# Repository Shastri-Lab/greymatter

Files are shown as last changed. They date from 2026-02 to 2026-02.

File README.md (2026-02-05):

# greymatter DAC controller

Embedded firmware for the Raspberry Pi Pico 2 (RP2350) controlling a multi-board DAC system for precision analog output generation. Designed for photonic neural network research applications.

## Features

- **24 DAC Control**: 8 daughter boards, each with 3 DACs (2x current, 1x voltage)
- **High Channel Count**: 112 current outputs + 32 voltage outputs = 144 total channels
- **SCPI Interface**: Standard instrument control commands over USB serial
- **Precision Output**:
  - Current: 3.125 mA to 300 mA full-scale (LTC2662)
  - Voltage: ±2.5V to ±10V bipolar, 0-10V unipolar (LTC2664)
- **16-bit Resolution**: 65,536 steps per channel
- **Fault Monitoring**: Per-DAC fault detection with interrupt support

## Hardware Requirements

- Raspberry Pi Pico 2 (RP2350)
- Greymatter motherboard with:
  - 3x MCP23S17 I/O expanders
  - TXB0106 level shifter
  - 8 daughter board slots
- Microcyte daughter boards (per slot):
  - 2x LTC2662 current DAC (5 channels each)
  - 1x LTC2664 voltage DAC (4 channels)

## Quick Start

### Prerequisites

```bash
# Set Pico SDK path
export PICO_SDK_PATH=/path/to/pico-sdk

# Required tools
# - CMake 3.13+
# - GCC ARM cross-compiler (gcc-15 recommended)
```

### Build

```bash
cd build
cmake .. -DPICO_BOARD=pico2
make picotoolBuild
C_INCLUDE_PATH= CPLUS_INCLUDE_PATH= make

# Optional: Custom SPI clock rate (default 10 MHz)
cmake .. -DPICO_BOARD=pico2 -DSPI_BAUDRATE=1000000  # 1 MHz for logic analyzer
make picotoolBuild && C_INCLUDE_PATH= CPLUS_INCLUDE_PATH= make
```

### Flash

1. Hold the **BOOTSEL** button on the Pico 2
2. Connect USB cable to computer
3. Copy `build/greymatter.uf2` to the `RPI-RP2` drive that appears
4. The Pico will reset and start running automatically

### Connect

```bash
# macOS/Linux
screen /dev/tty.usbmodem1101 115200

# Exit screen: Ctrl-A, K, Y
```

### Verify

```
*IDN?
```
Response: `greymatter,DAC Controller,001,0.1`

## Basic Usage

```bash
# Set voltage output (Board 0, DAC 2, Channel 0 to 5V)
BOARD0:DAC2:CH0:VOLT 5.0

# Set current output (Board 0, DAC 0, Channel 1 to 50mA)
BOARD0:DAC0:CH1:CURR 50.0

# Check for faults
FAULT?

# Reset all outputs
*RST
```

## Documentation

The **[user guide](docs/USER_GUIDE.md)** for the firmware contains a complete command reference, implementation details, calibration routines, and more details.

## Architecture

```
┌─────────────────────────────────────────────────────────────┐
│                     USB Serial (115200 baud)                │
└─────────────────────────────────────────────────────────────┘
                              │
                              ▼
┌─────────────────────────────────────────────────────────────┐
│                     SCPI Parser                             │
│              Command tokenization & validation              │
└─────────────────────────────────────────────────────────────┘
                              │
                              ▼
┌─────────────────────────────────────────────────────────────┐
│                     Board Manager                           │
│              Routes commands to 24 DACs                     │
└─────────────────────────────────────────────────────────────┘
                              │
              ┌───────────────┴───────────────┐
              ▼                               ▼
┌──────────────────────┐         ┌──────────────────────┐
│      LTC2662         │         │      LTC2664         │
│  Current DAC Driver  │         │  Voltage DAC Driver  │
│  (5 ch, 3-300 mA)    │         │  (4 ch, ±10V)        │
└──────────────────────┘         └──────────────────────┘
              │                               │
              └───────────────┬───────────────┘
                              ▼
┌─────────────────────────────────────────────────────────────┐
│                     SPI Manager                             │
│              Transaction coordination                       │
└─────────────────────────────────────────────────────────────┘
                              │
              ┌───────────────┴───────────────┐
              ▼                               ▼
┌──────────────────────┐         ┌──────────────────────┐
│    I/O Expanders     │         │    DAC Decoder       │
│  (MCP23S17 × 3)      │         │    (CS routing)      │
└──────────────────────┘         └──────────────────────┘
```

## Pin Assignments

| GPIO | Function | Description |
|---|---|---|
| GP16 | SPI_MISO | Data from DACs/expanders |
| GP17 | SPI_CS | Chip select (expanders only) |
| GP18 | SPI_CLK | SPI clock (configurable, default 10 MHz) |
| GP19 | SPI_MOSI | Data to DACs/expanders |
| GP20 | FAULT | Combined fault input |
| GP21 | LEVEL_SHIFT_OE | Level shifter enable |
| GP22 | EXPANDER_RESET | I/O expander reset |

## Project Structure

```
greymatter/
├── main.cpp              # Entry point, USB serial loop
├── scpi_parser.*         # SCPI command parsing
├── board_manager.*       # DAC routing and management
├── spi_manager.*         # SPI peripheral control
├── io_expander.*         # MCP23S17 driver
├── dac_device.*          # Abstract DAC interface
├── ltc2662.*             # Current DAC driver
├── ltc2664.*             # Voltage DAC driver
├── utils.*               # String parsing utilities
├── CMakeLists.txt        # Build configuration
├── docs/                 # Hardware programming guides
├── README.md             # This file
└── USER_GUIDE.md         # Detailed user documentation
```

## License
This software is licensed under the MIT license found at [LICENSE](LICENSE).

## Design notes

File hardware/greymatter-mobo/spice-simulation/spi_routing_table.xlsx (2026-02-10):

CS4 | CS3 | CS2 | CS1 | CS0 | D_EN0 | D_EN1 | D_EN2 | D_EN3 | CS_11 | CS_12 | CS_13 | CS_21 | CS_22 | CS_23 | CS_31 | CS_32 | CS_33 | CS_41 | CS_42 | CS_43 | CS_51 | CS_52 | CS_53 | CS_61 | CS_62 | CS_63 | CS_71 | CS_72 | CS_73 | CS_81 | CS_82 | CS_83
0 | 0 | 0 | 0 | 0 | 0 |  |  |  | 0
0 | 0 | 0 | 0 | 1 | 0 |  |  |  |  | 0
0 | 0 | 0 | 1 | 0 | 0 |  |  |  |  |  | 0
0 | 0 | 0 | 1 | 1 | 0 |  |  |  |  |  |  | 0
0 | 0 | 1 | 0 | 0 | 0 |  |  |  |  |  |  |  | 0
0 | 0 | 1 | 0 | 1 | 0 |  |  |  |  |  |  |  |  | 0
0 | 0 | 1 | 1 | 0 | 0 |  |  |  |  |  |  |  |  |  | 0
0 | 0 | 1 | 1 | 1 | 0 |  |  |  |  |  |  |  |  |  |  | 0
0 | 1 | 0 | 0 | 0 |  | 0 |  |  |  |  |  |  |  |  |  |  | 0
0 | 1 | 0 | 0 | 1 |  | 0 |  |  |  |  |  |  |  |  |  |  |  | 0
0 | 1 | 0 | 1 | 0 |  | 0 |  |  |  |  |  |  |  |  |  |  |  |  | 0
0 | 1 | 0 | 1 | 1 |  | 0 |  |  |  |  |  |  |  |  |  |  |  |  |  | 0
0 | 1 | 1 | 0 | 0 |  | 0 |  |  |  |  |  |  |  |  |  |  |  |  |  |  | 0
0 | 1 | 1 | 0 | 1 |  | 0 |  |  |  |  |  |  |  |  |  |  |  |  |  |  |  | 0
0 | 1 | 1 | 1 | 0 |  | 0 |  |  |  |  |  |  |  |  |  |  |  |  |  |  |  |  | 0
0 | 1 | 1 | 1 | 1 |  | 0 |  |  |  |  |  |  |  |  |  |  |  |  |  |  |  |  |  | 0
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

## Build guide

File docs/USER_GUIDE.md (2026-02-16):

# greymatter DAC controller - User Guide

This guide provides comprehensive documentation for operating the greymatter DAC Controller, including all available commands, addressing schemes, calibration procedures, and detailed implementation information.

## Table of Contents

1. [System Overview](#system-overview)
2. [Getting Started](#getting-started)
3. [Command Reference](#command-reference)
4. [Addressing Scheme](#addressing-scheme)
5. [Span Configuration](#span-configuration)
6. [Calibration](#calibration)
7. [Code Flow and Implementation Details](#code-flow-and-implementation-details)
8. [Hardware Architecture](#hardware-architecture)
9. [Troubleshooting](#troubleshooting)

---

## System Overview

The greymatter DAC Controller manages 24 Digital-to-Analog Converters distributed across 8 daughter boards. Each board contains:

- **2x LTC2662**: 5-channel current DACs (DAC 0 and DAC 1)
- **1x LTC2664**: 4-channel voltage DAC (DAC 2)

**Total outputs**: 80 current channels + 32 voltage channels = 112 independent analog outputs

### DAC Specifications

| DAC Type | Channels | Output Type | Range | Resolution |
|---|---|---|---|---|
| LTC2662 | 5 | Current | 3.125 mA - 300 mA | 12 or 16-bit |
| LTC2664 | 4 | Voltage | ±10V / 0-10V | 12 or 16-bit |

---

## Getting Started

### Connecting

1. Flash the firmware (see [README.md](../README.md))
2. Connect via USB serial at **115200 baud**
3. Wait for the startup banner

```bash
# macOS/Linux
screen /dev/tty.usbmodem1101 115200

# Windows (use PuTTY or similar)
# Select appropriate COM port, 115200 baud
```

### Startup Sequence

On power-up, the controller:
1. Initializes USB CDC serial interface
2. Waits for serial connection
3. Configures SPI and GPIO peripherals
4. Initializes all 24 DACs with default spans
5. Loads calibration data from flash (if present)
6. Reports any detected faults
7. Enters command loop

### First Commands

```
*IDN?                              # Verify connection
FAULT?                             # Check for hardware faults
BOARD0:DAC2:CH0:VOLT 1.0           # Set a voltage output
BOARD0:DAC0:CH0:CURR 10.0          # Set a current output
```

---

## Command Reference

All commands follow the SCPI (Standard Commands for Programmable Instruments) standard. Commands are case-insensitive and terminated with newline (`\n`).

### IEEE 488.2 Common Commands

| Command | Description | Response |
|---|---|---|
| `*IDN?` | Query device identification | `greymatter,DAC Controller,<SN>,0.1` |
| `*RST` | Reset all DACs to power-on state | `OK` |

### System Commands

| Command | Description | Response |
|---|---|---|
| `FAULT?` | Query 24-bit fault status | `OK` or `FAULT:0xNNNNNN` |
| `SYST:ERR?` | Query error queue | `0,No error` |
| `SYST:SN <string>` | Set controller serial number (max 31 chars, auto-saved to flash) | `OK` |
| `SYST:SN?` | Query controller serial number | Serial number or `(not set)` |
| `LDAC` | Pulse LDAC to update all outputs | `OK` |
| `UPDATE:ALL` | Update all DAC outputs | `OK` |

### Voltage Commands (LTC2664 - DAC 2 only)

| Command | Format | Example |
|---|---|---|
| Set Voltage | `BOARD<n>:DAC2:CH<c>:VOLT <value>` | `BOARD0:DAC2:CH0:VOLT 5.0` |
| Set Channel Span | `BOARD<n>:DAC2:CH<c>:SPAN <code>` | `BOARD0:DAC2:CH0:SPAN 3` |
| Set All Spans | `BOARD<n>:DAC2:SPAN:ALL <code>` | `BOARD0:DAC2:SPAN:ALL 3` |

### Current Commands (LTC2662 - DAC 0, DAC 1)

| Command | Format | Example |
|---|---|---|
| Set Current | `BOARD<n>:DAC<0-1>:CH<c>:CURR <value>` | `BOARD0:DAC0:CH0:CURR 50.0` |
| Set Channel Span | `BOARD<n>:DAC<0-1>:CH<c>:SPAN <code>` | `BOARD0:DAC0:CH0:SPAN 6` |
| Set All Spans | `BOARD<n>:DAC<0-1>:SPAN:ALL <code>` | `BOARD0:DAC0:SPAN:ALL 6` |

### Raw Code Commands (All DACs)

| Command | Format | Example |
|---|---|---|
| Set Code | `BOARD<n>:DAC<m>:CH<c>:CODE <value>` | `BOARD0:DAC0:CH0:CODE 32767` |
| Update DAC | `BOARD<n>:DAC<m>:UPDATE` | `BOARD0:DAC0:UPDATE` |

### Resolution Commands

| Command | Format | Description |
|---|---|---|
| Query Resolution | `BOARD<n>:DAC<m>:RES?` | Returns `12` or `16` |
| Set Resolution | `BOARD<n>:DAC<m>:RES <12\|16>` | Re-initializes DAC with new resolution |

### Power Management

| Command | Format | Description |
|---|---|---|
| Power Down Channel | `BOARD<n>:DAC<m>:CH<c>:PDOWN` | Powers down single channel |
| Power Down Chip | `BOARD<n>:DAC<m>:PDOWN` | Powers down entire DAC |

### Calibration Commands

| Command | Description | Response |
|---|---|---|
| `BOARD<n>:SN <string>` | Set board serial number | `OK` |
| `BOARD<n>:SN?` | Query board serial number | Serial number or `(not set)` |
| `BOARD<n>:DAC<m>:CH<c>:CAL:GAIN <value>` | Set gain factor | `OK` |
| `BOARD<n>:DAC<m>:CH<c>:CAL:GAIN?` | Query gain factor | Gain value |
| `BOARD<n>:DAC<m>:CH<c>:CAL:OFFS <value>` | Set offset | `OK` |
| `BOARD<n>:DAC<m>:CH<c>:CAL:OFFS?` | Query offset | Offset value |
| `BOARD<n>:DAC<m>:CH<c>:CAL:EN <0\|1>` | Enable/disable calibration | `OK` |
| `BOARD<n>:DAC<m>:CH<c>:CAL:EN?` | Query calibration enable | `0` or `1` |
| `CAL:DATA?` | Export all calibration data | Formatted data string |
| `CAL:SAVE` | Save calibration to flash | `OK` or error |
| `CAL:LOAD` | Load calibration from flash | `OK` or error |
| `CAL:CLEAR` | Clear all calibration data | `OK` |

### Command Examples

```bash
# === Voltage Output Examples ===

# Set Board 0, Voltage DAC, Channel 0 to +5V
BOARD0:DAC2:CH0:VOLT 5.0

# Set Board 3, Voltage DAC, Channel 2 to -3.3V (bipolar mode)
BOARD3:DAC2:CH2:VOLT -3.3

# Configure all voltage channels on Board 0 to ±10V range
BOARD0:DAC2:SPAN:ALL 3

# === Current Output Examples ===

# Set Board 0, Current DAC 0, Channel 1 to 50 mA
BOARD0:DAC0:CH1:CURR 50.0

# Set Board 5, Current DAC 1, Channel 4 to 100 mA
BOARD5:DAC1:CH4:CURR 100.0

# Configure all current channels on Board 2, DAC 0 to 200 mA range
BOARD2:DAC0:SPAN:ALL 7

# === Raw Code Examples ===

# Set mid-scale (32767 = 50% of full scale for 16-bit)
BOARD0:DAC0:CH0:CODE 32767

# Set maximum (65535 = 100% of full scale for 16-bit)
BOARD0:DAC0:CH0:CODE 65535

# === Resolution Examples ===

# Query current resolution
BOARD0:DAC0:RES?

# Set to 12-bit resolution
BOARD0:DAC0:RES 12

# === System Commands ===

# Check device identity
*IDN?

# Reset all DACs
*RST

# Check for faults
FAULT?

# Global LDAC pulse (update all pending outputs)
LDAC

# Power down a channel
BOARD0:DAC0:CH0:PDOWN

# Power down entire DAC chip
BOARD0:DAC0:PDOWN
```

---

## Addressing Scheme

### Board-DAC-Channel Hierarchy

```
BOARD<n>:DAC<m>:CH<c>
  │       │      │
  │       │      └── Channel: 0-4 (LTC2662) or 0-3 (LTC2664)
  │       │
  │       └── DAC: 0, 1 (current DAC - LTC2662)
  │                 2 (voltage DAC - LTC2664)
  │
  └── Board: 0-7 (8 daughter boards)
```

### DAC Index Calculation

Internally, DACs are indexed 0-23:

```
dac_index = (board_id × 3) + device_id
```

| Board | DAC 0 (LTC2662) | DAC 1 (LTC2662) | DAC 2 (LTC2664) |
|---|---|---|---|
| 0 | Index 0 | Index 1 | Index 2 |
| 1 | Index 3 | Index 4 | Index 5 |
| 2 | Index 6 | Index 7 | Index 8 |
| 3 | Index 9 | Index 10 | Index 11 |
| 4 | Index 12 | Index 13 | Index 14 |
| 5 | Index 15 | Index 16 | Index 17 |
| 6 | Index 18 | Index 19 | Index 20 |
| 7 | Index 21 | Index 22 | Index 23 |

### Channel Mapping

**LTC2662 (Current DAC)**:
- 5 channels: CH0, CH1, CH2, CH3, CH4
- Total per board: 10 current channels

**LTC2664 (Voltage DAC)**:
- 4 channels: CH0, CH1, CH2, CH3
- Total per board: 4 voltage channels

---

## Span Configuration

### LTC2662 Current DAC Spans

| Code | Full-Scale Current | Notes |
|---|---|---|
| 0x0 | Hi-Z (disabled) | Output disabled |
| 0x1 | 3.125 mA | |
| 0x2 | 6.25 mA | |
| 0x3 | 12.5 mA | |
| 0x4 | 25 mA | |
| 0x5 | 50 mA | |
| 0x6 | 100 mA | **Default** |
| 0x7 | 200 mA | |
| 0x8 | Switch to V- | Special mode |
| 0xF | 300 mA | Maximum |

**Example**: Set 200 mA range on Board 0, DAC 0:
```
BOARD0:DAC0:SPAN:ALL 7
```

### LTC2664 Voltage DAC Spans

| Code | Range | Type | Min | Max |
|---|---|---|-----|-----|
| 0 | 0V to 5V | Unipolar | 0V | +5V |
| 1 | 0V to 10V | Unipolar | 0V | +10V |
| 2 | ±5V | Bipolar | -5V | +5V |
| 3 | ±10V | Bipolar | -10V | +10V |
| 4 | ±2.5V | Bipolar | -2.5V | +2.5V |

**Default**: ±10V (code 3)

**Example**: Set ±5V range on Board 0, DAC 2:
```
BOARD0:DAC2:SPAN:ALL 2
```

### Output Calculations

**Current Output (LTC2662)**:
```
I_out = (code / max_code) × I_fullscale
```

**Voltage Output (LTC2664)**:
```
Unipolar: V_out = (code / max_code) × V_max
Bipolar:  V_out = V_min + (code / max_code) × (V_max - V_min)
```

Where `max_code` is 4095 for 12-bit or 65535 for 16-bit resolution.

---

## Calibration

The greymatter firmware supports two-point linear calibration for each DAC channel to correct for gain and offset errors.

### Calibration Model

```
calibrated_output = (ideal_output × gain) + offset
```

Where:
- `ideal_output` is the requested voltage (V) or current (mA)
- `gain` is the gain correction factor (nominally 1.0)
- `offset` is the offset correction in physical units (nominally 0.0)

### Equipment Required

- Keithley Source-Measure Unit (SMU) or equivalent high-precision meter
  - For voltage DACs (LTC2664): Voltage measurement with at least 6-digit resolution
  - For current DACs (LTC2662): Current measurement with at least 6-digit resolution
- Test leads appropriate for the output being measured
- Temperature-stable environment (allow 30 minutes warm-up)

### Two-Point Calibration Procedure

The goal is to characterize the transfer function of each DAC channel by measuring the actual output at two known setpoints, then computing correction factors.

Given:
- Point 1: Set `V_set_low`, measure `V_meas_low`
- Point 2: Set `V_set_high`, measure `V_meas_high`

**Calibration factor calculation:**

```
gain_cal = (V_set_high - V_set_low) / (V_meas_high - V_meas_low)
offset_cal = V_set_low - (gain_cal × V_meas_low)
```

### Procedure for LTC2664 (Voltage DAC)

1. **Setup**
   - Connect SMU to the voltage output under test
   - Configure SMU for voltage measurement (high-Z input)
   - Ensure appropriate span is set for the channel

2. **Set calibration points**
   - For bipolar spans (±10V, ±5V, ±2.5V): Use 10% and 90% of range
   - For unipolar spans (0-5V, 0-10V): Use 10% and 90% of range

   Example for ±10V span:
   ```
   Low point:  -8.0V (10% from -10V)
   High point: +8.0V (90% toward +10V)
   ```

3. **Measure low point**
   ```
   BOARD0:DAC2:CH0:VOLT -8.0
   OK
   ```
   Record SMU reading: `V_meas_low = -8.0123` (example)

4. **Measure high point**
   ```
   BOARD0:DAC2:CH0:VOLT 8.0
   OK
   ```
   Record SMU reading: `V_meas_high = +7.9987` (example)

5. **Calculate calibration factors**
   ```
   gain_cal = (8.0 - (-8.0)) / (7.9987 - (-8.0123))
           = 16.0 / 16.011
           = 0.999313

   offset_cal = -8.0 - (0.999313 × (-8.0123))
             = -8.0 - (-8.0068)
             = 0.0068
   ```

6. **Apply calibration**
   ```
   BOARD0:DAC2:CH0:CAL:GAIN 0.999313
   OK
   BOARD0:DAC2:CH0:CAL:OFFS 0.0068
   OK
   BOARD0:DAC2:CH0:CAL:EN 1
   OK
   ```

7. **Verify calibration**
   ```
   BOARD0:DAC2:CH0:VOLT -8.0
   ```
   SMU should now read closer to -8.000V

### Procedure for LTC2662 (Current DAC)

1. **Setup**
   - Connect SMU to the current output under test
   - Configure SMU for current measurement (low burden voltage)
   - Set appropriate span for expected current range

2. **Set calibration points**
   - Use 10% and 90% of the configured span

   Example for 100mA span:
   ```
   Low point:  10.0 mA
   High point: 90.0 mA
   ```

3. **Measure low point**
   ```
   BOARD0:DAC0:CH0:CURR 10.0
   OK
   ```
   Record SMU reading: `I_meas_low = 10.015` mA (example)

4. **Measure high point**
   ```
   BOARD0:DAC0:CH0:CURR 90.0
   OK
   ```
   Record SMU reading: `I_meas_high = 89.985` mA (example)

5. **Calculate calibration factors**
   ```
   gain_cal = (90.0 - 10.0) / (89.985 - 10.015)
           = 80.0 / 79.970
           = 1.000375

   offset_cal = 10.0 - (1.000375 × 10.015)
             = 10.0 - 10.0188
             = -0.0188
   ```

6. **Apply calibration**
   ```
   BOARD0:DAC0:CH0:CAL:GAIN 1.000375
   OK
   BOARD0:DAC0:CH0:CAL:OFFS -0.0188
   OK
   BOARD0:DAC0:CH0:CAL:EN 1
   OK
   ```

7. **Verify calibration**
   ```
   BOARD0:DAC0:CH0:CURR 50.0
   ```
   SMU should now read closer to 50.000 mA

### Controller Identification

Each Pico controller can be assigned a unique serial number to identify it when multiple controllers are connected via USB. This is stored in a separate flash sector from calibration data, so `CAL:CLEAR` will not erase it.

```
# Set controller serial number (auto-saved to flash)
SYST:SN GM-CTRL-001
OK

# Query controller serial number
SYST:SN?
GM-CTRL-001

# Serial number appears in *IDN? response
*IDN?
greymatter,DAC Controller,GM-CTRL-001,0.1
```

The serial number also appears in the startup banner and is used by the ZMQ server to name discovered controllers.

### Storing Calibration Data

Calibration data is stored in the RP2350's onboard flash memory, in the last 4KB sector (offset 0x1FF000).

**Workflow**:
1. Perform calibration using the procedures above
2. Save to flash: `CAL:SAVE`
3. Calibration persists across power cycles

**Automatic Loading**: On power-up, the firmware automatically loads calibration data from flash if valid data is found.

**Example session**:
```
# Set calibration for a channel
BOARD0:DAC2:CH0:CAL:GAIN 0.999313
OK
BOARD0:DAC2:CH0:CAL:OFFS 0.0068
OK
BOARD0:DAC2:CH0:CAL:EN 1
OK

# Save to flash
CAL:SAVE
OK

# Power cycle the device...

# After power-up, verify calibration was loaded
BOARD0:DAC2:CH0:CAL:GAIN?
0.999313
BOARD0:DAC2:CH0:CAL:EN?
1
```

### Export Format

The `CAL:DATA?` command returns calibration data in a human-readable format:

```
BOARD0:SN=GM-2024-001
  DAC2:CH0:G=0.999313,O=0.006800,E=1
  DAC2:CH1:G=1.000125,O=-0.003200,E=1
BOARD1:SN=GM-2024-002
  DAC0:CH0:G=1.000375,O=-0.018800,E=1
```

### Flash Storage Details

- **Location**: Last 4KB sector of 2MB flash (offset 0x1FF000)
- **Data integrity**: CRC-16 checksum validates stored data
- **Magic number**: 0x47524D43 ("GRMC") identifies valid calibration data
- **Wear leveling**: Flash is only written when `CAL:SAVE` is explicitly called
- **Sector erase**: Each save erases and rewrites the entire sector (typical flash endurance: 100,000 cycles)

### Calibration Best Practices

1. **Temperature stability**: Allow 30 minutes warm-up before calibrating
2. **Calibration points**: Use 10% and 90% of range to capture the full transfer function
3. **Verification**: Always verify calibration by measuring at the midpoint
4. **Documentation**: Record serial numbers and calibration dates
5. **Periodic recalibration**: Recalibrate annually or after significant temperature excursions
6. **Per-span calibration**: If using multiple spans, consider calibrating each span separately

### Automated Calibration Script

Here's a Python example for automated calibration using PyVISA:

```python
import pyvisa
import time

# Initialize instruments
rm = pyvisa.ResourceManager()
keithley = rm.open_resource('GPIB0::24::INSTR')  # Adjust address
greymatter = rm.open_resource('ASRL/dev/tty.usbmodem1101::INSTR')

def calibrate_voltage_channel(board, dac, channel, span_min, span_max):
    """Calibrate a voltage DAC channel."""

    # Calculate calibration points (10% and 90% of range)
    v_low = span_min + 0.1 * (span_max - span_min)
    v_high = span_min + 0.9 * (span_max - span_min)

    # Measure low point
    greymatter.write(f'BOARD{board}:DAC{dac}:CH{channel}:VOLT {v_low}')
    time.sleep(0.5)  # Allow settling
    v_meas_low = float(keithley.query(':MEAS:VOLT?'))

    # Measure high point
    greymatter.write(f'BOARD{board}:DAC{dac}:CH{channel}:VOLT {v_high}')
    time.sleep(0.5)
    v_meas_high = float(keithley.query(':MEAS:VOLT?'))

    # Calculate calibration factors
    gain = (v_high - v_low) / (v_meas_high - v_meas_low)
    offset = v_low - (gain * v_meas_low)

    # Apply calibration
    greymatter.write(f'BOARD{board}:DAC{dac}:CH{channel}:CAL:GAIN {gain:.6f}')
    greymatter.write(f'BOARD{board}:DAC{dac}:CH{channel}:CAL:OFFS {offset:.6f}')
    greymatter.write(f'BOARD{board}:DAC{dac}:CH{channel}:CAL:EN 1')

    print(f'Board {board}, DAC {dac}, CH {channel}:')
    print(f'  Gain: {gain:.6f}, Offset: {offset:.6f} V')

    return gain, offset

# Example: Calibrate Board 0, DAC 2 (voltage), all channels
for ch in range(4):
    calibrate_voltage_channel(0, 2, ch, -10.0, 10.0)

# Save calibration to flash
greymatter.write('CAL:SAVE')
```

---

## Code Flow and Implementation Details

This section describes the internal implementation for developers and advanced users.

### 1. System Initialization

When the firmware starts, the following initialization sequence occurs:

```
main()
│
├─► stdio_init_all()
│   Initialize USB CDC for serial communication
│
├─► Wait for tud_cdc_connected()
│   Block until a serial terminal connects
│
├─► SpiManager::init()
│   │
│   ├─► init_gpio()
│   │   ├── GP21 = HIGH (enable TXB0106 level shifter) [CRITICAL FIRST]
│   │   ├── GP22 = output (expander reset)
│   │   ├── GP20 = input + pull-up (fault detection)
│   │   └── GP17 = output, HIGH (SPI chip select)
│   │
│   ├─► init_spi()
│   │   ├── spi_init(spi0, SPI_BAUDRATE)  // Configurable, default 10 MHz
│   │   ├── Configure GP16 (MISO), GP18 (CLK), GP19 (MOSI)
│   │   └── SPI Mode 0 (CPOL=0, CPHA=0)
│   │
│   ├─► reset_io_expanders()
│   │   ├── GP22 = LOW for 10µs
│   │   └── GP22 = HIGH, wait 100µs
│   │
│   └─► IoExpander::init(spi0)
│       ├── Enable HAEN on all expanders (address broadcast)
│       ├── Configure EXPANDER_0 (CS bits, D_EN, LDAC, CLR)
│       ├── Configure EXPANDER_1 (FAULT0-15 inputs)
│       └── Configure EXPANDER_2 (FAULT16-23 inputs)
│
├─► BoardManager::init_all()
│   │
│   ├─► For each board (0-7):
│   │   ├── Create LTC2662 instances (DAC 0, 1)
│   │   │   └── init(): set_span_all(0x6), update_all()
│   │   │
│   │   └── Create LTC2664 instance (DAC 2)
│   │       └── init(): set_span_all(0x3), update_all()
│   │
│   └─► CalStorage::load_from_flash()
│       └── Load calibration data if valid
│
├─► Check initial fault status
│   └── If GP20 is LOW, read and report fault mask
│
└─► Enter main command loop
```

### 2. Command Processing Flow

```
main loop
│
├─► Read line from USB serial
│   └── Accumulate characters until '\n' or '\r'
│
├─► ScpiParser::parse(line)
│   │
│   ├─► Skip leading whitespace
│   │
│   ├─► Try parse_common_command()
│   │   └── Match *IDN?, *RST
│   │
│   ├─► Try parse_system_command()
│   │   └── Match FAULT?, SYST:ERR?, LDAC, UPDATE:ALL, CAL:*
│   │
│   └─► Try parse_board_command()
│       ├── Extract BOARD<n>
│       ├── Extract :DAC<m> or :SN
│       └── Parse subcommand:
│           ├── CH<c>:VOLT, CH<c>:CURR, CH<c>:CODE
│           ├── CH<c>:SPAN, CH<c>:PDOWN, CH<c>:CAL:*
│           ├── SPAN:ALL, RES
│           ├── UPDATE
│           └── PDOWN
│
├─► BoardManager::execute(cmd)
│   │
│   └─► Switch on command type:
│       │
│       ├─► SET_VOLTAGE
│       │   ├── Validate: DAC must be 2 (LTC2664)
│       │   ├── Apply calibration if enabled
│       │   ├── Get span range from LTC2664_SPAN_INFO[]
│       │   ├── Clamp voltage to range
│       │   ├── Calculate: code = normalize(voltage) × max_code
│       │   └── dac->send_command(WRITE_UPDATE_N, channel, code)
│       │
│       ├─► SET_CURRENT
│       │   ├── Validate: DAC must be 0 or 1 (LTC2662)
│       │   ├── Apply calibration if enabled
│       │   ├── Get full-scale from span setting
│       │   ├── Clamp current to 0..full_scale
│       │   ├── Calculate: code = (current / full_scale) × max_code
│       │   └── dac->send_command(WRITE_UPDATE_N, channel, code)
│       │
│       └─► ... (other commands)
│
└─► Send response via USB serial
```

### 3. SPI Transaction Flow

Every DAC command involves a multi-step SPI transaction:

```
SpiManager::transaction(board_id, device_id, tx_buf, rx_buf, len)
│
├─► Step 1: Select DAC via I/O Expander
│   │
│   └─► IoExpander::set_dac_select(board_id, device_id)
│       ├── Calculate dac_index = board_id × 3 + device_id
│       ├── Set CS0-CS4 bits (5-bit address)
│       ├── Set D_EN bit HIGH (enable decoder tree)
│       ├── Write to EXPANDER_0 Port A
│       └── sleep_us(1)  // Decoder settling
│
├─► Step 2: SPI Transfer to DAC
│   │
│   ├── NOTE: CS (GP17) is NOT asserted here
│   │   The decoder tree provides chip select to the DAC
│   │
│   └── spi_write_read_blocking(spi0, tx_buf, rx_buf, len)
│
├─► sleep_us(1)  // Data latch time
│
└─► Step 3: Deselect DAC
    │
    └─► IoExpander::deselect_dac()
        ├── Clear D_EN bit (disable decoder)
        └── Write to EXPANDER_0 Port A
```

### 4. DAC Command Format (24-bit SPI)

```
┌─────────────────────────────────────────────────────────────┐
│  Byte 0 (MSB)      │  Byte 1          │  Byte 2 (LSB)      │
├────────┬───────────┼──────────────────┼────────────────────┤
│ Command│  Address  │    Data[15:8]    │    Data[7:0]       │
│  [7:4] │   [3:0]   │                  │                    │
└────────┴───────────┴──────────────────┴────────────────────┘

DacDevice::send_command(command, address, data):
    tx_buf[0] = ((command & 0x0F) << 4) | (address & 0x0F)
    tx_buf[1] = (data >> 8) & 0xFF
    tx_buf[2] = data & 0xFF
```

**Command Codes**:

| Code | Name | Description |
|---|---|---|
| 0x0 | WRITE_N | Write code to input register |
| 0x1 | UPDATE_N | Copy input to DAC register |
| 0x2 | WRITE_ALL_UPDATE_ALL | Write all, update all |
| 0x3 | WRITE_UPDATE_N | Write and update single channel |
| 0x4 | POWER_DOWN_N | Power down channel |
| 0x5 | POWER_DOWN_CHIP | Power down entire chip |
| 0x6 | WRITE_SPAN_N | Set span for channel |
| 0x7 | CONFIG | Configuration register |
| 0x8 | WRITE_ALL | Write to all channels |
| 0x9 | UPDATE_ALL | Update all channels |
| 0xA | WRITE_ALL_UPDATE_ALL | Write all, update all |
| 0xB | MUX | Monitor/analog mux |
| 0xE | WRITE_SPAN_ALL | Set span for all channels |
| 0xF | NOP | No operation |

### 5. I/O Expander Operations

The three MCP23S17 expanders are addressed via hardware pins:

```
EXPANDER_0 (Address 0x0): Control signals
├── Port A [7:0]:
│   ├── [4:0] CS0-CS4: 5-bit DAC address (bit-reversed)
│   └── [5]   D_EN: Decoder enable
└── Port B [7:0]:
    ├── [0]   LDAC: Load DAC (active-low)
    └── [7]   CLR: Clear (active-low)

EXPANDER_1 (Address 0x1): Fault inputs 0-15
├── Port A [7:0]: Boards 0-3, DACs 0-1 (active-low)
└── Port B [7:0]: Boards 4-7, DACs 0-1 (active-low)

EXPANDER_2 (Address 0x2): Temperature fault inputs
└── Port A [7:0]: All 8 boards, DAC 2 (active-low)
```

**MCP23S17 SPI Protocol**:

```
Write: [0x40 | (addr << 1) | 0] [register] [data]
Read:  [0x40 | (addr << 1) | 1] [register] → [data]
```

### 6. Fault Detection

```
Fault Monitoring:
│
├─► Hardware: GP20 connected to OR'd FAULT outputs
│   └── Active-low: LOW = at least one fault
│
├─► FAULT? Command:
│   ├── Check GP20 state
│   │
│   ├── If HIGH (no fault):
│   │   └── Return "OK"
│   │
│   └── If LOW (fault present):
│       ├── Read EXPANDER_1 GPIO (faults 0-15)
│       ├── Read EXPANDER_2 Port A (faults 16-23)
│       ├── Invert bits (active-low → active-high)
│       ├── Reorganize to DAC index order
│       └── Return "FAULT:0xNNNNNN"
│
└─► Bit Position Mapping:
    Bit 0  → Board 0, DAC 0
    Bit 1  → Board 0, DAC 1
    Bit 2  → Board 0, DAC 2
    ...
    Bit 23 → Board 7, DAC 2
```

---

## Hardware Architecture

### Block Diagram

```
                                    ┌─────────────────────────────────────┐
                                    │         Daughter Board 0            │
                                    │  ┌─────────┐ ┌─────────┐ ┌────────┐ │
                              ┌────►│  │ LTC2662 │ │ LTC2662 │ │LTC2664 │ │
                              │     │  │ DAC 0   │ │ DAC 1   │ │ DAC 2  │ │
                              │     │  │ 5ch I   │ │ 5ch I   │ │ 4ch V  │ │
                              │     │  └─────────┘ └─────────┘ └────────┘ │
┌──────────────┐              │     └─────────────────────────────────────┘
│              │              │                        ⋮
│   RP2350     │    SPI       │     ┌─────────────────────────────────────┐
│  (Pico 2)    │◄────────────►│     │         Daughter Board 7            │
│              │              │     │  ┌─────────┐ ┌─────────┐ ┌────────┐ │
│  GP16 MISO   │              └────►│  │ LTC2662 │ │ LTC2662 │ │LTC2664 │ │
│  GP17 CS     │                    │  │ DAC 21  │ │ DAC 22  │ │ DAC 23 │ │
│  GP18 CLK    │     ┌──────────┐   │  │ 5ch I   │ │ 5ch I   │ │ 4ch V  │ │
│  GP19 MOSI   │────►│ TXB0106  │   │  └─────────┘ └─────────┘ └────────┘ │
│              │     │ Level    │   └─────────────────────────────────────┘
│  GP20 FAULT◄─┼─────│ Shifter  │
│  GP21 OE────►│     └──────────┘
│  GP22 RST───►│            │
│              │            ▼
└──────────────┘   ┌──────────────────────────────────┐
                   │     MCP23S17 I/O Expanders       │
                   │ ┌────────┐ ┌────────┐ ┌────────┐ │
                   │ │ EXP 0  │ │ EXP 1  │ │ EXP 2  │ │
                   │ │CS,LDAC │ │FAULT   │ │FAULT   │ │
                   │ │CLR,DEN │ │ 0-15   │ │ 16-23  │ │
                   │ └────────┘ └────────┘ └────────┘ │
                   └──────────────────────────────────┘
                              │
                              ▼
                   ┌──────────────────┐
                   │  Decoder Tree    │
                   │  (5-to-24 CS)    │
                   └──────────────────┘
```

### Signal Flow

1. **Commands** arrive via USB serial (115200 baud)
2. **SCPI Parser** tokenizes and validates the command
3. **Board Manager** routes to the appropriate DAC driver
4. **DAC Driver** constructs the 24-bit SPI command
5. **SPI Manager** orchestrates the multi-step transaction:
   - Sets decoder address via I/O expander
   - Sends SPI data to DAC
   - Deselects DAC
6. **Response** sent back via USB serial

### Critical Timing

| Operation | Minimum Time | Code Implementation |
|---|---|---|
| Level shifter enable to SPI | 0 µs | Set GP21 first thing in init |
| Expander reset pulse | 10 µs low | `sleep_us(10)` |
| Expander reset recovery | 100 µs | `sleep_us(100)` |
| Decoder settling | 1 µs | `sleep_us(1)` |
| DAC data latch | 1 µs | `sleep_us(1)` |
| LDAC pulse width | 20 ns min | `sleep_us(1)` |

---

## Troubleshooting

### No Response from Device

1. **Check USB connection**: Device should enumerate as USB CDC
2. **Verify baud rate**: Must be 115200
3. **Check terminal settings**: No hardware flow control
4. **Try `*IDN?`**: Should return identification string

### FAULT? Returns Non-Zero

The fault mask indicates which DACs have faults:

```
FAULT:0x000001  → DAC 0 (Board 0, DAC 0) has fault
FAULT:0x000004  → DAC 2 (Board 0, DAC 2) has fault
FAULT:0x800000  → DAC 23 (Board 7, DAC 2) has fault
```

**Common causes**:
- Overcurrent condition (LTC2662)
- Thermal shutdown
- Output shorted
- Power supply issue

### Output Not Changing

1. **Check span setting**: Output must be within configured span
2. **Verify addressing**: Board (0-7), DAC (0-2), Channel varies by DAC type
3. **Try raw code**: `BOARD0:DAC0:CH0:CODE 32767` (mid-scale)
4. **Issue LDAC**: `LDAC` to update all outputs

### Current/Voltage Out of Range

The firmware clamps values to the configured span:

```bash
# If span is 100 mA (code 6):
BOARD0:DAC0:CH0:CURR 200.0  # Clamped to 100 mA

# If span is ±5V (code 2):
BOARD0:DAC2:CH0:VOLT 8.0    # Clamped to +5V
```

**Solution**: Set appropriate span first:
```bash
BOARD0:DAC0:SPAN:ALL 7      # 200 mA range
BOARD0:DAC2:SPAN:ALL 3      # ±10V range
```

### Calibration Not Applied

- Verify calibration is enabled: `BOARD<n>:DAC<m>:CH<c>:CAL:EN?` should return `1`
- Check gain and offset values are reasonable (gain near 1.0, offset near 0)

### Calibration Lost After Power Cycle

- Ensure `CAL:SAVE` was called after setting calibration
- Verify calibration was loaded: `BOARD<n>:DAC<m>:CH<c>:CAL:EN?` should return `1`
- Check for valid data in flash: `CAL:LOAD` should return `OK`
- If flash is corrupted, recalibrate and save again

### Build Errors

1. **Check PICO_SDK_PATH**: Must point to valid Pico SDK installation
2. **Verify compiler**: ARM cross-compiler required
3. **Clean build**: Delete `build/` directory and rebuild

```bash
rm -rf build
mkdir build
cd build
cmake .. -DPICO_BOARD=pico2
make picotoolBuild
C_INCLUDE_PATH= CPLUS_INCLUDE_PATH= make
```

---

## Appendix: Source File Reference

| File | Purpose |
|---|---|
| `main.cpp` | Entry point, USB serial loop |
| `scpi_parser.cpp/hpp` | SCPI command parsing |
| `board_manager.cpp/hpp` | DAC routing and execution |
| `spi_manager.cpp/hpp` | SPI peripheral control |
| `io_expander.cpp/hpp` | MCP23S17 driver |
| `dac_device.cpp/hpp` | Abstract DAC base class |
| `ltc2662.cpp/hpp` | Current DAC driver |
| `ltc2664.cpp/hpp` | Voltage DAC driver |
| `cal_storage.cpp/hpp` | Flash-based calibration persistence |
| `utils.cpp/hpp` | String utilities |

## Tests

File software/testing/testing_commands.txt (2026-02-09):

// when terminal connects, initialization sequence should begin
// we expect FAULT light on because DAC0:CH4 is open circuit (designed that way on board)

// power down open-circuit channel, fault light should go off
BOARD0:DAC1:CH4:PDOWN

// setting all channels with current/voltage mode
BOARD0:DAC0:CH0:CURR 0.3
BOARD0:DAC0:CH1:CURR 0.6
BOARD0:DAC0:CH2:CURR 0.9
BOARD0:DAC0:CH3:CURR 1.2
BOARD0:DAC0:CH4:CURR 1.5
BOARD0:DAC1:CH0:CURR 0.3
BOARD0:DAC1:CH1:CURR 0.6
BOARD0:DAC1:CH2:CURR 0.9
BOARD0:DAC1:CH3:CURR 1.2
BOARD0:DAC1:CH4:CURR 1.5
BOARD0:DAC2:CH0:VOLT 1.0
BOARD0:DAC2:CH1:VOLT 2.0
BOARD0:DAC2:CH2:VOLT 3.0

// setting all channels with mid-scale codes
BOARD0:DAC0:CH0:CODE 32767
BOARD0:DAC0:CH1:CODE 32767
BOARD0:DAC0:CH2:CODE 32767
BOARD0:DAC0:CH3:CODE 32767
BOARD0:DAC0:CH4:CODE 32767
BOARD0:DAC1:CH0:CODE 32767
BOARD0:DAC1:CH1:CODE 32767
BOARD0:DAC1:CH2:CODE 32767
BOARD0:DAC1:CH3:CODE 32767
BOARD0:DAC1:CH4:CODE 32767
BOARD0:DAC2:CH0:CODE 2048
BOARD0:DAC2:CH1:CODE 2048
BOARD0:DAC2:CH2:CODE 2048

//powering down all chips
BOARD0:DAC0:PDOWN
BOARD0:DAC1:PDOWN
BOARD0:DAC2:PDOWN

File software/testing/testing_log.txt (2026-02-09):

MCT0001-1 - old paste, stencil - good
- stopped working after IPA clean
- I think I7, I6 were still working, but not all channels
- gave it a second IPA bath, air in a can, then 1 hr under a fan, more air in a can, dropped it on the ground, then put it on warm surface (Keithley 2606B) for 1 hr

MCT0001-2 - old paste, stencil - good
- gave it an IPA bath but haven't tested yet
- gave it a second IPA bath, air in a can, then 1 hr under a fan, more air in a can, then put it on warm surface (Keithley 2606B) for 1 hr

MCT0014-1 - sam + hugh collab - only some current channels, fault light went on, then off, but never back on again (even when it should have)
- H, W6, W8 working
- sam touched up solder; mostly working; VN and W4 don't work
- hugh touched up solder; all good

MCT0014-2 - sam + hugh collab 2 - only voltage channels, no fault light ever
- Vn, Vp, Vb working
- no evidence that communication even works with other DACs (PDOWN doesn't change current)
- 4mA through V+ and 3mA through V- when everything is "powered down"
- sam touched up solder; W1,2,3,4,5 don't work
 -- clearly data unconnected
- hugh touched up solder; all good

MCT0014-3 - Sam solo, sparse solder paste
- nothing working, no fault lights
- sam touched up solder; still doesn't work

MCT0014-4 - new paste, stencil, hugh touch up - good

MCT0014-5 - sam soldered (new paste, stencil? no touch up) - good
- hugh accidentally removed the chip from testing rig without ESD protection; haven't tested for damage yet

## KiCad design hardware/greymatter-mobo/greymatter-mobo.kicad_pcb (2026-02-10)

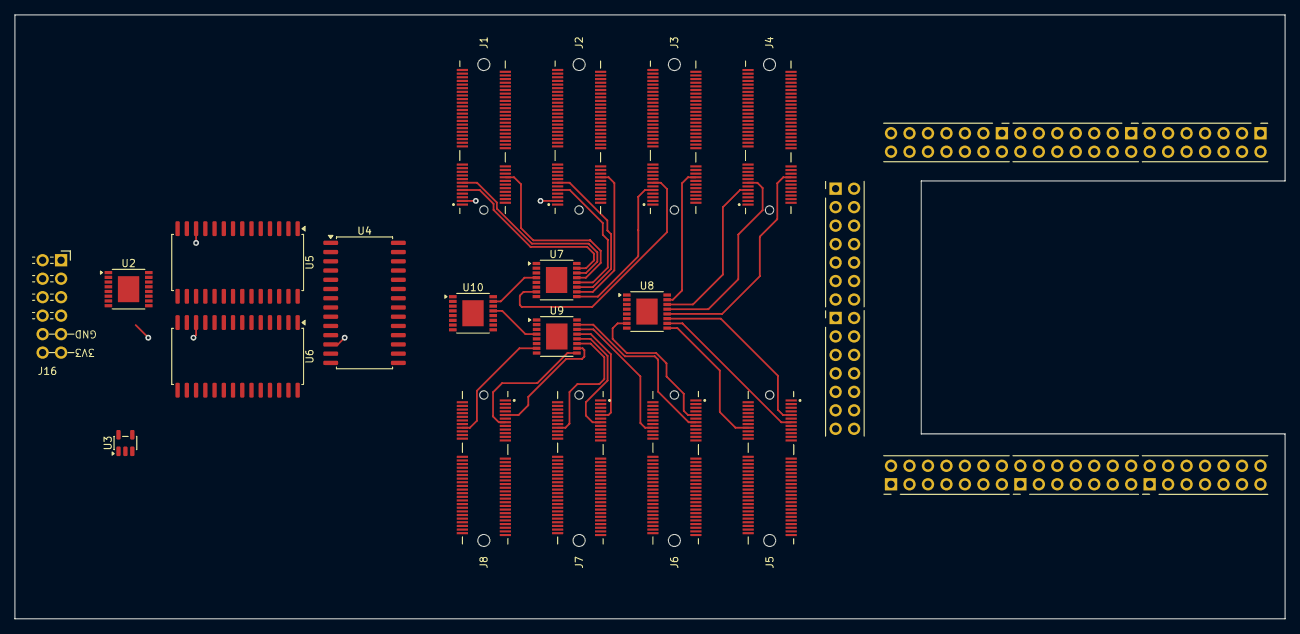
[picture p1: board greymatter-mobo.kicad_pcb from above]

Board: 6 copper layers, 174.6 x 83.0 mm, 18 parts (0 on the bottom side), 79 nets.

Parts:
J1, J2, J3, J4, J5, J6, J7, J8: M2-J-67-V-SMT-5.30-KE-KT; ADAMTECH_M2-J-67-V-SMT-5.30-KE-KT
J16: Conn_01x12; PinHeader_2x06_PMOD_Peripheral
U2: TXB0106RGYR; TSSOP-16-1EP_4.4x5mm_P0.65mm
U3: 74LVC1G32; SOT-23-5
U4, U5, U6: MCP23S17_SO; SOIC-28W_7.5x17.9mm_P1.27mm
U7, U8, U9, U10: SN74LVC138ARGYR; TSSOP-16-1EP_4.4x5mm_P0.65mm

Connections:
+3V3: J16.6, J16.12, U2.2 (VCCA)
+5V: J1.4, J1.21, J2.4, J2.21, J3.4, J3.21, J4.4, J4.21, J5.4, J5.21, J6.4, J6.21, J7.4, J7.21, J8.4, J8.21, U2.15 (VCCB), U3.5 (VCC), U4.9 (VDD), U5.9 (VDD), U5.15 (A0), U6.9 (VDD), U6.16 (A1), U7.6 (G1), U7.16 (VCC), U8.6 (G1), U8.16 (VCC), U9.6 (G1), U9.16 (VCC), U10.16 (VCC)
+10V: J1.34, J1.35, J1.36, J1.37, J2.34, J2.35, J2.36, J2.37, J3.34, J3.35, J3.36, J3.37, J4.34, J4.35, J4.36, J4.37, J5.34, J5.35, J5.36, J5.37, J6.34, J6.35, J6.36, J6.37, J7.34, J7.35, J7.36, J7.37, J8.34, J8.35, J8.36, J8.37
-10V: J1.70, J1.71, J1.72, J1.73, J2.70, J2.71, J2.72, J2.73, J3.70, J3.71, J3.72, J3.73, J4.70, J4.71, J4.72, J4.73, J5.70, J5.71, J5.72, J5.73, J6.70, J6.71, J6.72, J6.73, J7.70, J7.71, J7.72, J7.73, J8.70, J8.71, J8.72, J8.73
CLRDAC: J1.10, J2.10, J3.10, J4.10, J5.10, J6.10, J7.10, J8.10
CS: U2.16 (B1), U4.11 (~CS), U5.11 (~CS), U6.11 (~CS), U10.6 (G1)
CS0: U4.25 (GPA4), U7.1 (A), U8.1 (A), U9.1 (A)
CS1: U4.24 (GPA3), U7.2 (B), U8.2 (B), U9.2 (B)
CS2: U4.23 (GPA2), U7.3 (C), U8.3 (C), U9.3 (C)
CS3: U4.22 (GPA1), U10.1 (A)
CS4: U4.21 (GPA0), U10.2 (B)
CS_3V3: J16.1, U2.1 (A1)
CS_11: J1.7, U7.15 (Y0)
CS_12: J1.5, U7.14 (Y1)
CS_13: J1.3, U7.13 (Y2)
CS_21: J2.7, U7.12 (Y3)
CS_22: J2.5, U7.11 (Y4)
CS_23: J2.3, U7.10 (Y5)
CS_31: J3.7, U7.9 (Y6)
CS_32: J3.5, U7.7 (Y7)
CS_33: J3.3, U8.15 (Y0)
CS_41: J4.7, U8.14 (Y1)
CS_42: J4.5, U8.13 (Y2)
CS_43: J4.3, U8.12 (Y3)
CS_51: J5.7, U8.11 (Y4)
CS_52: J5.5, U8.10 (Y5)
CS_53: J5.3, U8.9 (Y6)
CS_61: J6.7, U8.7 (Y7)
CS_62: J6.5, U9.15 (Y0)
CS_63: J6.3, U9.14 (Y1)
CS_71: J7.7, U9.13 (Y2)
CS_72: J7.5, U9.12 (Y3)
CS_73: J7.3, U9.11 (Y4)
CS_81: J8.7, U9.10 (Y5)
CS_82: J8.5, U9.9 (Y6)
CS_83: J8.3, U9.7 (Y7)
DAC_FAULT: U3.2, U5.20 (INTA)
DEN: U4.26 (GPA5), U7.5 (*G2B), U8.5 (*G2B), U9.5 (*G2B)
D_EN0: U7.4 (*G2A), U10.15 (Y0)
D_EN1: U8.4 (*G2A), U10.14 (Y1)
D_EN2: U9.4 (*G2A), U10.13 (Y2)
FAULT: U2.10 (B6), U3.4
FAULT_3V3: J16.7, U2.7 (A6)
FAULT_11: J1.19, U5.21 (GPA0)
FAULT_12: J1.18, U5.22 (GPA1)
FAULT_21: J2.19, U5.23 (GPA2)
FAULT_22: J2.18, U5.24 (GPA3)
FAULT_31: J3.19, U5.25 (GPA4)
FAULT_32: J3.18, U5.26 (GPA5)
FAULT_41: J4.19, U5.27 (GPA6)
FAULT_42: J4.18, U5.28 (GPA7)
FAULT_51: J5.19, U5.1 (GPB0)
FAULT_52: J5.18, U5.2 (GPB1)
FAULT_61: J6.19, U5.3 (GPB2)
FAULT_62: J6.18, U5.4 (GPB3)
FAULT_71: J7.19, U5.5 (GPB4)
FAULT_72: J7.18, U5.6 (GPB5)
FAULT_81: J8.19, U5.7 (GPB6)
FAULT_82: J8.18, U5.8 (GPB7)
GND: J1.1, J1.2, J1.8, J1.11, J1.13, J1.14, J1.15, J1.17, J1.22, J1.23, J1.32, J1.33, J1.38, J1.39, J1.40, J1.41, J1.44, J1.45, J1.48, J1.49, J1.52, J1.53, J1.56, J1.57, J1.60, J1.61, J1.64, J1.65, J1.68, J1.69, J1.74, J1.75, J2.1, J2.2, J2.8, J2.11, J2.13, J2.14, J2.15, J2.17, J2.22, J2.23, J2.32, J2.33, J2.38, J2.39, J2.40, J2.41, J2.44, J2.45, J2.48, J2.49, J2.52, J2.53, J2.56, J2.57, J2.60, J2.61, J2.64, J2.65, J2.68, J2.69, J2.74, J2.75, J3.1, J3.2, J3.8, J3.11, J3.13, J3.14, J3.15, J3.17, J3.22, J3.23, J3.32, J3.33, J3.38, J3.39, J3.40, J3.41, J3.44, J3.45, J3.48, J3.49, J3.52, J3.53, J3.56, J3.57, J3.60, J3.61, J3.64, J3.65, J3.68, J3.69, J3.74, J3.75, J4.1, J4.2, J4.8, J4.11, J4.13, J4.14, J4.15, J4.17, J4.22, J4.23, J4.32, J4.33, J4.38, J4.39, J4.40, J4.41, J4.44, J4.45, J4.48, J4.49, J4.52, J4.53, J4.56, J4.57, J4.60, J4.61, J4.64, J4.65, J4.68, J4.69, J4.74, J4.75, J5.1, J5.2, J5.8, J5.11, J5.13, J5.14, J5.15, J5.17, J5.22, J5.23, J5.32, J5.33, J5.38, J5.39, J5.40, J5.41, J5.44, J5.45, J5.48, J5.49, J5.52, J5.53, J5.56, J5.57, J5.60, J5.61, J5.64, J5.65, J5.68, J5.69, J5.74, J5.75, J6.1, J6.2, J6.8, J6.11, J6.13, J6.14, J6.15, J6.17, J6.22, J6.23, J6.32, J6.33, J6.38, J6.39, J6.40, J6.41, J6.44, J6.45, J6.48, J6.49, J6.52, J6.53, J6.56, J6.57, J6.60, J6.61, J6.64, J6.65, J6.68, J6.69, J6.74, J6.75, J7.1, J7.2, J7.8, J7.11, J7.13, J7.14, J7.15, J7.17, J7.22, J7.23, J7.32, J7.33, J7.38, J7.39, J7.40, J7.41, J7.44, J7.45, J7.48, J7.49, J7.52, J7.53, J7.56, J7.57, J7.60, J7.61, J7.64, J7.65, J7.68, J7.69, J7.74, J7.75, J8.1, J8.2, J8.8, J8.11, J8.13, J8.14, J8.15, J8.17, J8.22, J8.23, J8.32, J8.33, J8.38, J8.39, J8.40, J8.41, J8.44, J8.45, J8.48, J8.49, J8.52, J8.53, J8.56, J8.57, J8.60, J8.61, J8.64, J8.65, J8.68, J8.69, J8.74, J8.75, J16.5, J16.11, U2.9 (GND), U2.17 (EPAD), U3.3 (GND), U4.10 (VSS), U4.15 (A0), U4.16 (A1), U4.17 (A2), U5.10 (VSS), U5.16 (A1), U5.17 (A2), U6.10 (VSS), U6.15 (A0), U6.17 (A2), U7.8 (GND), U7.17 (EPAD), U8.8 (GND), U8.17 (EPAD), U9.8 (GND), U9.17 (EPAD), U10.3 (C), U10.4 (*G2A), U10.5 (*G2B), U10.8 (GND), U10.17 (EPAD)
LDAC: J1.16, J2.16, J3.16, J4.16, J5.16, J6.16, J7.16, J8.16, U4.1 (GPB0)
MISO: J1.6, J2.6, J3.6, J4.6, J5.6, J6.6, J7.6, J8.6, U2.12 (B4), U4.14 (SO), U5.14 (SO), U6.14 (SO)
MISO_3V3: J16.3, U2.5 (A4)
MOSI: J1.9, J2.9, J3.9, J4.9, J5.9, J6.9, J7.9, J8.9, U2.13 (B3), U4.13 (SI), U5.13 (SI), U6.13 (SI)
MOSI_3V3: J16.2, U2.4 (A3)
OE_3V3: J16.9, U2.8 (OE)
RESET: U2.11 (B5), U4.18 (~RESET), U5.18 (~RESET), U6.18 (~RESET)
RESET_3V3: J16.8, U2.6 (A5)
SCK_3V3: J16.4, U2.3 (A2)
SCLK: J1.12, J2.12, J3.12, J4.12, J5.12, J6.12, J7.12, J8.12, U2.14 (B2), U4.12 (SCK), U5.12 (SCK), U6.12 (SCK)
TEMP1: J1.20, U6.21 (GPA0)
TEMP2: J2.20, U6.22 (GPA1)
TEMP3: J3.20, U6.23 (GPA2)
TEMP4: J4.20, U6.24 (GPA3)
TEMP5: J5.20, U6.25 (GPA4)
TEMP6: J6.20, U6.26 (GPA5)
TEMP7: J7.20, U6.27 (GPA6)
TEMP8: J8.20, U6.28 (GPA7)
TEMP_FAULT: U3.1, U6.20 (INTA)

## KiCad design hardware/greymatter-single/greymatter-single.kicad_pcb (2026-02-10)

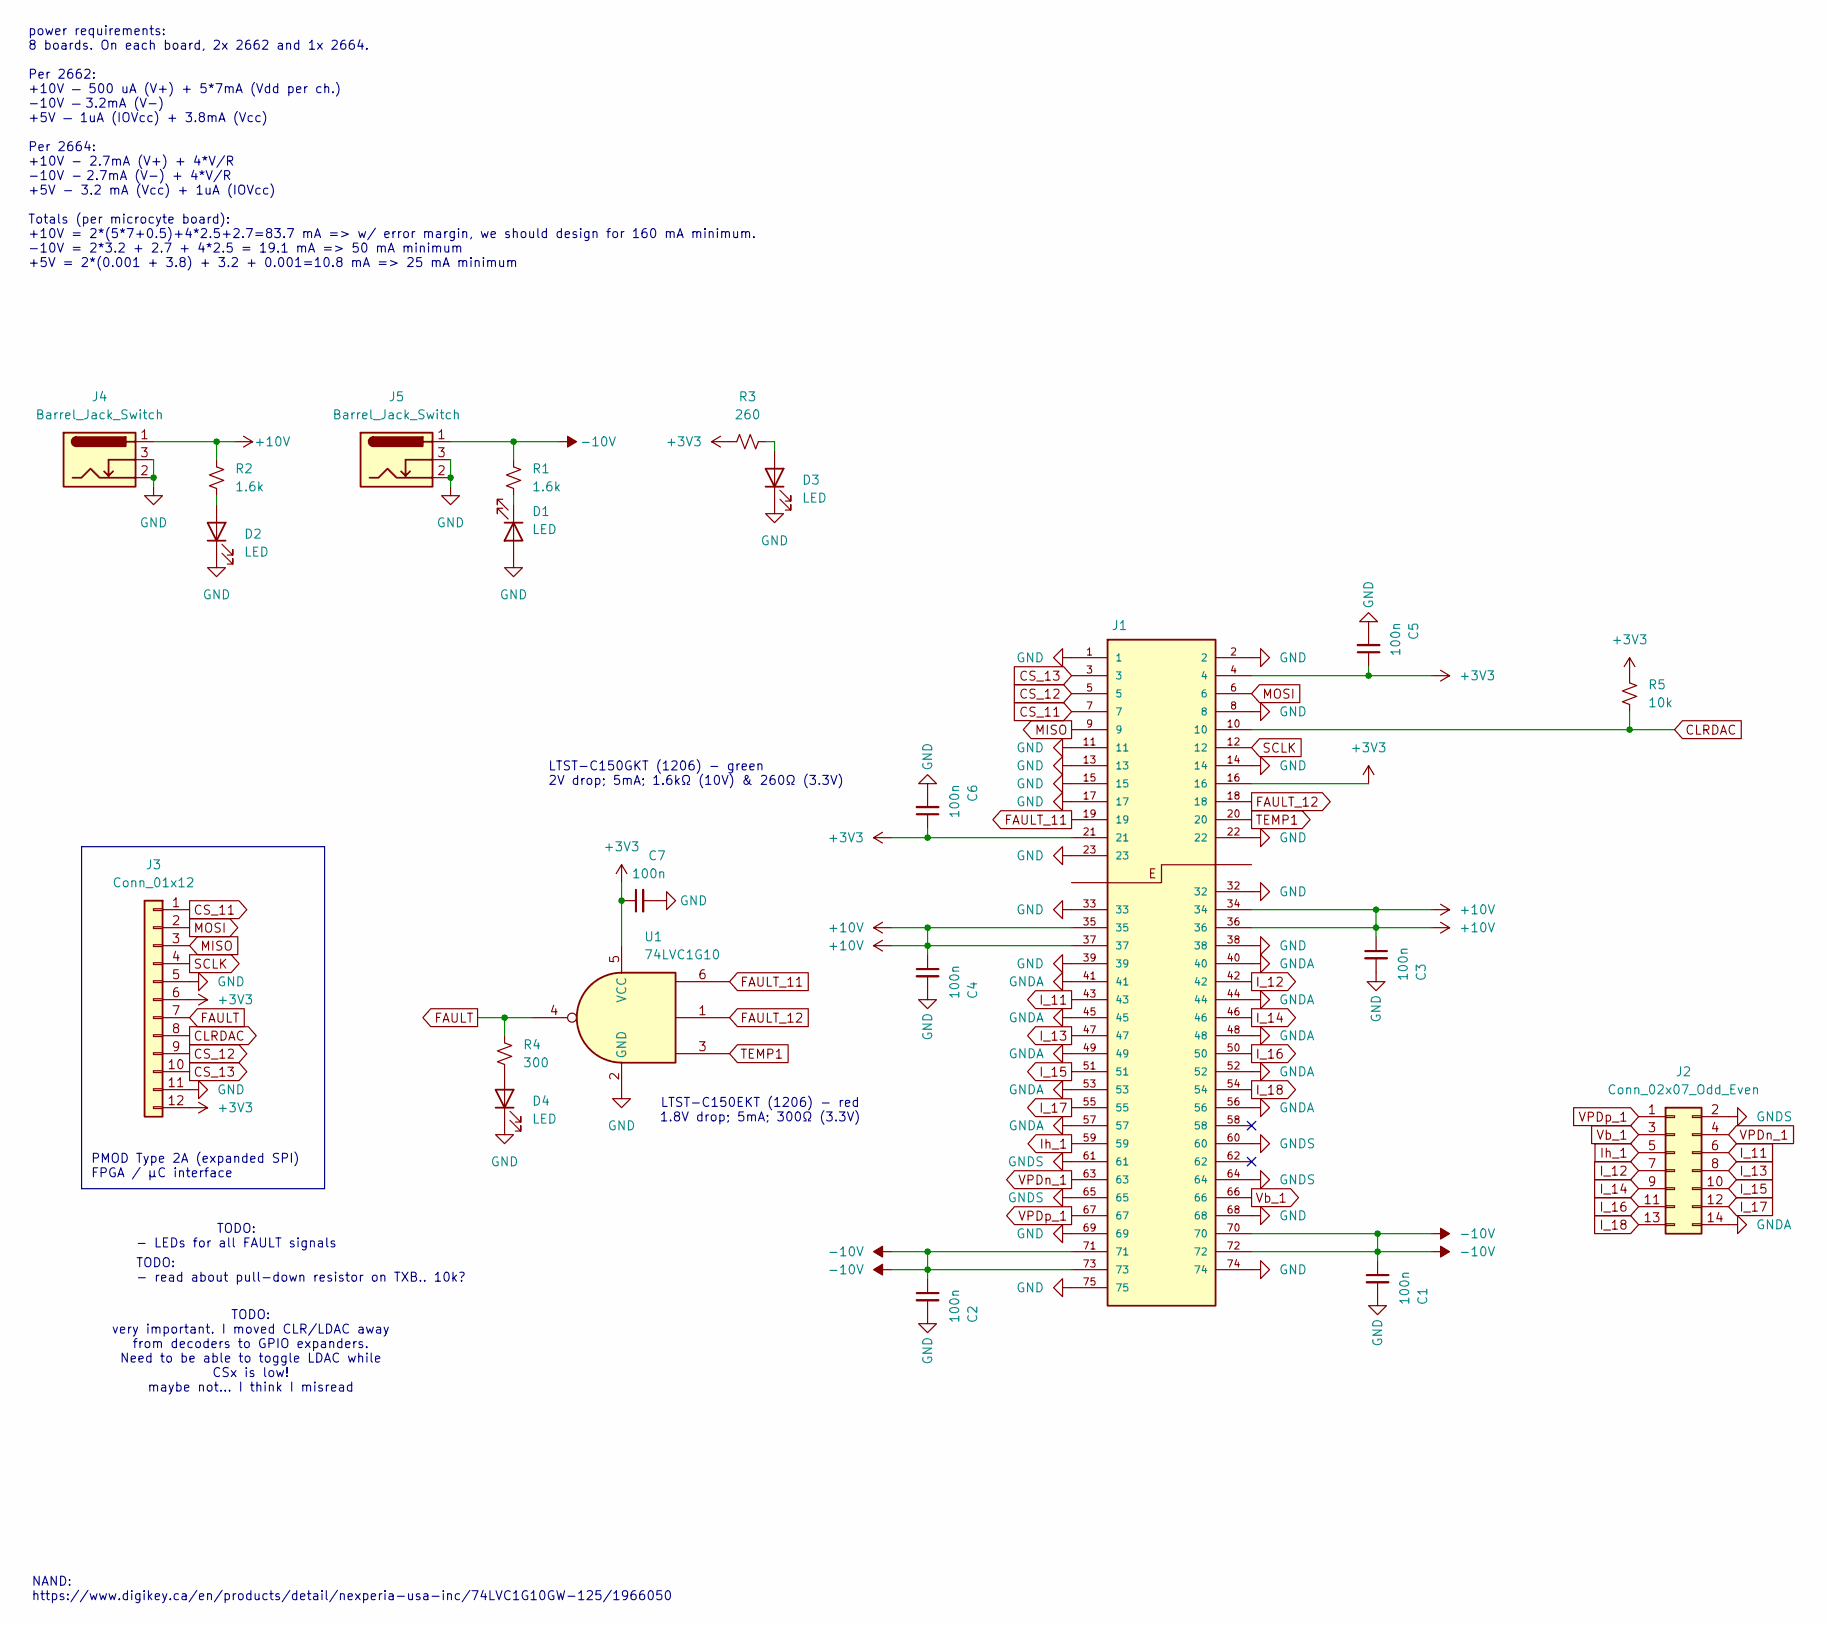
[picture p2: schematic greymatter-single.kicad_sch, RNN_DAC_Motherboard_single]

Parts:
C1, C2, C3, C4, C5, C6, C7: 100n; C_1206_3216Metric
D1, D2, D3, D4: LED; D_1206_3216Metric
J1: M2-J-67-V-SMT-5.30-KE-KT; ADAMTECH_M2-J-67-V-SMT-5.30-KE-KT; PARTREV 2
J2: Conn_02x07_Odd_Even; PinSocket_2x07_P2.54mm_Vertical
J3: Conn_01x12; PinHeader_2x06_PMOD_Peripheral_Vertical
J4, J5: Barrel_Jack_Switch; CUI_PJ-044A
R1, R2: 1.6k; R_1206_3216Metric
R3: 260; R_1206_3216Metric
R4: 300; R_1206_3216Metric
R5: 10k; R_1206_3216Metric
U1: 74LVC1G10; SOT-457T

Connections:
+3V3: C5.1, C6.1, C7.1, J1.4, J1.16, J1.21, J3.6, J3.12, R3.1, R5.2, U1.5 (VCC)
+10V: C3.1, C4.1, J1.34, J1.35, J1.36, J1.37, J4.1, R2.1
-10V: C1.1, C2.1, J1.70, J1.71, J1.72, J1.73, J5.1, R1.1
CLRDAC: J1.10, J3.8, R5.1
CS_11: J1.7, J3.1
CS_12: J1.5, J3.9
CS_13: J1.3, J3.10
FAULT: J3.7, R4.2, U1.4
FAULT_11: J1.19, U1.6
FAULT_12: J1.18, U1.1
GND: C1.2, C2.2, C3.2, C4.2, C5.2, C6.2, C7.2, D1.2 (A), D2.1 (K), D3.1 (K), D4.1 (K), J1.1, J1.2, J1.8, J1.11, J1.13, J1.14, J1.15, J1.17, J1.22, J1.23, J1.32, J1.33, J1.38, J1.39, J1.68, J1.69, J1.74, J1.75, J3.5, J3.11, J4.2, J4.3, J5.2, J5.3, U1.2 (GND)
GNDA: J1.40, J1.41, J1.44, J1.45, J1.48, J1.49, J1.52, J1.53, J1.56, J1.57, J2.14
GNDS: J1.60, J1.61, J1.64, J1.65, J2.2
I_11: J1.43, J2.6
I_12: J1.42, J2.7
I_13: J1.47, J2.8
I_14: J1.46, J2.9
I_15: J1.51, J2.10
I_16: J1.50, J2.11
I_17: J1.55, J2.12
I_18: J1.54, J2.13
Ih_1: J1.59, J2.5
MISO: J1.9, J3.3
MOSI: J1.6, J3.2
unnamed: D1.1 (K), R1.2
unnamed: D2.2 (A), R2.2
unnamed: D3.2 (A), R3.2
unnamed: D4.2 (A), R4.1
SCLK: J1.12, J3.4
TEMP1: J1.20, U1.3
VPDn_1: J1.63, J2.4
VPDp_1: J1.67, J2.1
Vb_1: J1.66, J2.3

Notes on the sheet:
LTST-C150GKT (1206) - green 2V drop; 5mA; 1.6kΩ (10V) & 260Ω (3.3V)
PMOD Type 2A (expanded SPI) FPGA / µC interface
TODO: very important. I moved CLR/LDAC away from decoders to GPIO expanders. Need to be able to toggle LDAC while CSx is low! maybe not... I think I misread
TODO: - read about pull-down resistor on TXB.. 10k?
NAND: https://www.digikey.ca/en/products/detail/nexperia-usa-inc/74LVC1G10GW-125/1966050
LTST-C150EKT (1206) - red 1.8V drop; 5mA; 300Ω (3.3V)
TODO: - LEDs for all FAULT signals
power requirements: 8 boards. On each board, 2x 2662 and 1x 2664. Per 2662: +10V — 500 uA (V+) + 5*7mA (Vdd per ch.) -10V — 3.2mA (V-) +5V — 1uA (IOVcc) + 3.8mA (Vcc) Per 2664: +10V - 2.7mA (V+) + 4*V/R -10V - 2.7mA (V-) + 4*V/R +5V - 3.2 mA (Vcc) + 1uA (IOVcc) Totals (per microcyte board): +10V = 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

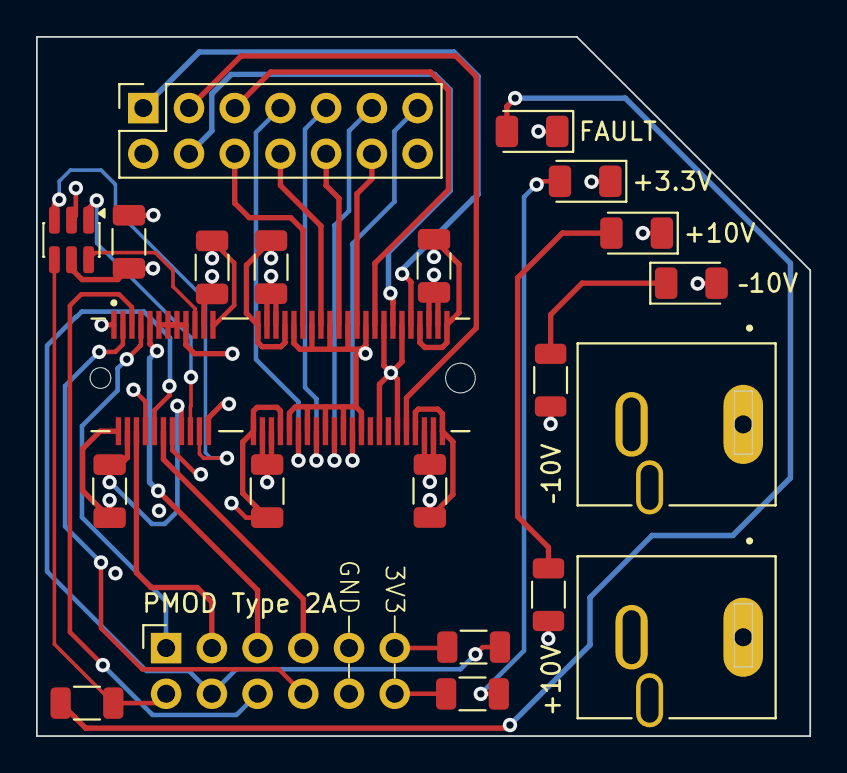
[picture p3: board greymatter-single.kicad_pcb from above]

Board: 4 copper layers, 43.0 x 38.8 mm, 22 parts (0 on the bottom side), 33 nets.

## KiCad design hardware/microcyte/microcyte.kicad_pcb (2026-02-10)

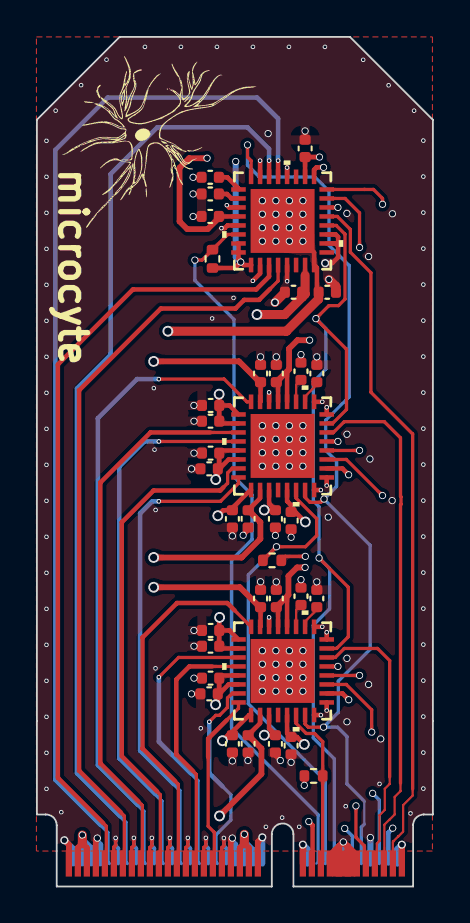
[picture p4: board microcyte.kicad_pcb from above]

Board: 6 copper layers, 22.0 x 47.2 mm, 37 parts (0 on the bottom side), 35 nets.

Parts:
C1, C3, C5: 47n; C_0402_1005Metric
C2, C4, C6, C16, C26, C29: 100n; C_0402_1005Metric
C7, C8, C9, C10, C11, C12, C13, C14, C15, C17, C18, C19, C20, C21, C22, C23, C24, C25, C27, C28, C30: 1u; C_0402_1005Metric
J1: Conn_02x38_Odd_Even; Connector_M.2_key-E
R1, R3, R5: 10k; R_0402_1005Metric
U1, U2: LTC2662HUH-12-PBF; 05-08-1693_ADI
U3: LTC2664HUH-12-PBF; 05-08-1693_ADI

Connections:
+5V: C15.1, C16.1, C25.1, C26.1, C29.1, C30.1, J1.4, J1.21, R1.1, R3.1, R5.1, U1.2 (TGP), U1.12 (FSADJ), U1.13 (VCC), U1.29 (IOVCC), U2.2 (TGP), U2.12 (FSADJ), U2.13 (VCC), U2.29 (IOVCC), U3.1 (MSP2), U3.17 (TGP), U3.18 (IOVCC), U3.28 (VCC), U3.31 (MSP0), U3.32 (MSP1)
+10V: C7.1, C8.1, C9.1, C10.1, C11.1, C12.1, C17.1, C18.1, C19.1, C20.1, C21.1, C22.1, C27.1, J1.34, J1.35, J1.36, J1.37, U1.17 (VDD4), U1.18 (VDD3), U1.21 (VDD2), U1.22 (VDD1), U1.25 (VDD0), U1.27 (V+), U2.17 (VDD4), U2.18 (VDD3), U2.21 (VDD2), U2.22 (VDD1), U2.25 (VDD0), U2.27 (V+), U3.7 (V+)
-10V: C13.1, C14.1, C23.1, C24.1, C28.1, J1.70, J1.71, J1.72, J1.73, U1.15 (V-), U1.26 (V-), U2.15 (V-), U2.26 (V-), U3.8 (V), U3.33 (EPAD)
CLR: J1.10, U1.31 (*CLR), U2.31 (*CLR), U3.24 (*CLR)
FAULT1: J1.19, R3.2, U1.30 (*FAULT)
FAULT2: J1.18, R1.2, U2.30 (*FAULT)
GND: C1.2, C2.2, C3.2, C4.2, C5.2, C6.2, C7.2, C8.2, C9.2, C10.2, C11.2, C12.2, C13.2, C14.2, C15.2, C16.2, C17.2, C18.2, C19.2, C20.2, C21.2, C22.2, C23.2, C24.2, C25.2, C26.2, C27.2, C28.2, C29.2, C30.2, J1.1, J1.2, J1.8, J1.11, J1.13, J1.14, J1.15, J1.17, J1.22, J1.23, J1.32, J1.33, J1.38, J1.39, J1.40, J1.41, J1.44, J1.45, J1.48, J1.49, J1.52, J1.53, J1.56, J1.57, J1.60, J1.61, J1.64, J1.65, J1.68, J1.69, J1.74, J1.75, U1.1 (GND), U1.8 (GND), U1.9 (REFLO), U1.14 (GND), U1.32 (GND), U1.33 (GND), U2.1 (GND), U2.8 (GND), U2.9 (REFLO), U2.14 (GND), U2.32 (GND), U2.33 (GND), U3.2 (MUXIN0), U3.5 (MUXIN1), U3.10 (REFLO), U3.11 (GND), U3.20 (MUXIN2), U3.23 (MUXIN3), U3.27 (REFLO), U3.29 (GND)
I0: J1.43, U1.24 (OUT0)
I1: J1.42, U1.23 (OUT1)
I2: J1.47, U1.20 (OUT2)
I3: J1.46, U1.19 (OUT3)
I4: J1.51, U1.16 (OUT4)
I5: J1.50, U2.24 (OUT0)
I6: J1.55, U2.23 (OUT1)
I7: J1.54, U2.20 (OUT2)
I8: J1.59, U2.19 (OUT3)
I9: J1.58, U2.16 (OUT4)
LDAC: J1.16, U1.7 (*LDAC), U2.7 (*LDAC), U3.12 (*LDAC)
MISO: J1.9, U1.4 (SDO), U2.4 (SDO), U3.15 (SDO)
MOSI: J1.6, U1.3 (SDI), U2.3 (SDI), U3.16 (SDI)
unnamed: C3.1, U1.10 (REF)
unnamed: C4.1, U1.11 (REFCOMP)
unnamed: C5.1, U2.10 (REF)
unnamed: C6.1, U2.11 (REFCOMP)
unnamed: C1.1, U3.25 (REF)
unnamed: C2.1, U3.26 (REFCOMP)
SCLK: J1.12, U1.5 (SCK), U2.5 (SCK), U3.14 (SCK)
SS1: J1.7, U1.6 (*CS/LD)
SS2: J1.5, U2.6 (*CS/LD)
SS3: J1.3, U3.13 (*CS/LD)
TEMP: J1.20, R5.2, U3.30 (*OVRTMP)
Vb0: J1.67, U3.3 (VOUT0)
Vb1: J1.63, U3.4 (VOUT1)
Vb2: J1.66, U3.21 (VOUT2)
Vb3: J1.62, U3.22 (VOUT3)

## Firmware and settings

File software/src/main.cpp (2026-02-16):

// main loop: initialize all peripherals, enter command parsing loop
#include <stdio.h>
#include <cstring>
#include <string>
#include "pico/stdlib.h"
#include "hardware/spi.h"
#include "tusb.h" // tinyusb, for usb serial

#include "scpi_parser.hpp"
#include "board_manager.hpp"
#include "spi_manager.hpp"

// Line buffer for serial input
static constexpr size_t LINE_BUFFER_SIZE = 256;
static char line_buffer[LINE_BUFFER_SIZE];
static size_t line_pos = 0;

// Global instances
static SpiManager spi_manager;
static ScpiParser parser;

// Read a line from USB serial (non-blocking)
// Returns true if a complete line was read
static bool read_line() {
    while (true) {
        int c = getchar_timeout_us(0);
        if (c == PICO_ERROR_TIMEOUT) {
            return false;
        }

        if (c == '\r' || c == '\n') {
            if (line_pos > 0) {
                line_buffer[line_pos] = '\0';
                line_pos = 0;
                return true;
            }
            // Skip empty lines
            continue;
        }

        if (c == '\b' || c == 127) {
            // Handle backspace
            if (line_pos > 0) {
                line_pos--;
                printf("\b \b");  // Erase character on terminal
            }
            continue;
        }

        // Only accept printable ASCII characters
        if (c >= 0x20 && c <= 0x7E && line_pos < LINE_BUFFER_SIZE - 1) {
            line_buffer[line_pos++] = static_cast<char>(c);
            putchar(c);  // Echo character
        }
    }
}

int main() {
    // Initialize USB stdio
    stdio_init_all();

    // Wait for USB connection (optional, helps with debugging)
    while (!tud_cdc_connected()) {
        sleep_ms(100);
    }
    sleep_ms(100);  // Extra settle time

    // Print startup banner
    printf("\r\n");
    printf("greymatter DAC Controller v0.1\r\n");
#ifdef SINGLE_BOARD_MODE
    printf("Mode: Single-board (1 board, 3 DACs, direct GPIO CS)\r\n");
#else
    printf("Mode: Multi-board (8 boards, 24 DACs, IO expander CS)\r\n");
#endif
    printf("SPI clock: %lu Hz\r\n", (unsigned long)SPI_CONFIG::BAUDRATE);
    printf("Initializing...\r\n");

    // Initialize SPI manager (includes GPIO, SPI peripheral, IO expanders)
    spi_manager.init();
    printf("SPI and IO expanders initialized.\r\n");

    // Initialize board manager with all DACs
    BoardManager board_manager(spi_manager);
    board_manager.init_all();
    printf("All DACs initialized.\r\n");

    // Print controller serial number if set
    const char* ctrl_sn = board_manager.get_controller_serial();
    if (ctrl_sn[0] != '\0') {
        printf("Controller S/N: %s\r\n", ctrl_sn);
    }

    // Check for any initial faults
    if (spi_manager.is_fault_active()) {
        printf("WARNING: FAULT line is active!\r\n");
#ifndef SINGLE_BOARD_MODE
        uint32_t faults = spi_manager.io_expander().read_faults();
        printf("Fault mask: 0x%06lX\r\n", faults);
#else
        printf("(Cannot identify which DAC in single-board mode)\r\n");
#endif
    } else {
        printf("No faults detected.\r\n");
    }

    // Flush any garbage from USB buffer before accepting commands
    while (getchar_timeout_us(0) != PICO_ERROR_TIMEOUT) {}

    printf("Ready. Enter SCPI commands:\r\n");
    printf("> ");

    // Main command loop
    while (true) {
        if (read_line()) {
            printf("\r\n");

            // Parse and execute SCPI command
            ScpiCommand cmd = parser.parse(line_buffer);
            std::string response = board_manager.execute(cmd);

            // Print response
            printf("%s\r\n", response.c_str());
            printf("> ");
        }

        // Brief yield to allow USB processing
        tud_task();
    }

    return 0;
}

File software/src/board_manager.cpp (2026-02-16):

#include "board_manager.hpp"
#include "utils.hpp"
#include "cal_storage.hpp"
#include <cstdio>
#include <cstring>

BoardManager::BoardManager(SpiManager& spi) : spi_(spi) {
    // Initialize controller serial number to empty
    controller_serial_[0] = '\0';

    // Initialize DAC pointers and storage
    // Each board has: DAC0=LTC2662, DAC1=LTC2662, DAC2=LTC2664
    for (uint8_t board = 0; board < NUM_BOARDS; board++) {
        // LTC2662 current DACs (device_id 0 and 1)
        current_dacs_[board][0] = nullptr;
        current_dacs_[board][1] = nullptr;
        voltage_dacs_[board] = nullptr;

        // Set default resolutions
        resolution_[board][0] = DEFAULT_CURRENT_DAC_RESOLUTION;
        resolution_[board][1] = DEFAULT_CURRENT_DAC_RESOLUTION;
        resolution_[board][2] = DEFAULT_VOLTAGE_DAC_RESOLUTION;

        // Initialize serial numbers to empty
        serial_numbers_[board][0] = '\0';

        // Initialize calibration to defaults (gain=1, offset=0, disabled)
        for (uint8_t dac = 0; dac < DACS_PER_BOARD; dac++) {
            for (uint8_t ch = 0; ch < MAX_CHANNELS_PER_DAC; ch++) {
                calibration_[board][dac][ch].gain = 1.0f;
                calibration_[board][dac][ch].offset = 0.0f;
                calibration_[board][dac][ch].enabled = false;
            }
        }
    }
}

void BoardManager::init_all() {
    // Setup and initialize all DAC devices
    for (uint8_t board = 0; board < NUM_BOARDS; board++) {
        // Setup LTC2662 current DACs at device_id 0 and 1
        uint8_t idx0 = board * 2;
        uint8_t idx1 = board * 2 + 1;

        current_dac_storage_[idx0].setup(&spi_, board, 0, resolution_[board][0]);
        current_dac_storage_[idx1].setup(&spi_, board, 1, resolution_[board][1]);
        current_dacs_[board][0] = &current_dac_storage_[idx0];
        current_dacs_[board][1] = &current_dac_storage_[idx1];

        // Setup LTC2664 voltage DAC at device_id 2
        voltage_dac_storage_[board].setup(&spi_, board, 2, resolution_[board][2]);
        voltage_dacs_[board] = &voltage_dac_storage_[board];

        // Initialize each DAC
        current_dacs_[board][0]->init();
        current_dacs_[board][1]->init();
        voltage_dacs_[board]->init();
    }

    // Load calibration data from flash (if valid data exists)
    CalStorage::load_from_flash(*this);

    // Load controller serial number from flash (separate sector)
    CalStorage::load_controller_sn(controller_serial_, SERIAL_NUMBER_MAX_LEN);
}

void BoardManager::reset_all() {
    // Power down and re-initialize all DACs
    for (uint8_t board = 0; board < NUM_BOARDS; board++) {
        if (current_dacs_[board][0]) current_dacs_[board][0]->power_down_chip();
        if (current_dacs_[board][1]) current_dacs_[board][1]->power_down_chip();
        if (voltage_dacs_[board]) voltage_dacs_[board]->power_down_chip();
    }

    // Re-initialize
    init_all();
}

DacDevice* BoardManager::get_dac(uint8_t board, uint8_t dac) {
    if (board >= NUM_BOARDS || dac >= DACS_PER_BOARD) {
        return nullptr;
    }

    if (dac < 2) {
        return current_dacs_[board][dac];
    } else {
        return voltage_dacs_[board];
    }
}

uint8_t BoardManager::get_dac_type(uint8_t board, uint8_t dac) {
    // 0 = LTC2662 (current), 1 = LTC2664 (voltage)
    return (dac == 2) ? 1 : 0;
}

void BoardManager::set_resolution(uint8_t board, uint8_t dac, uint8_t resolution_bits) {
    if (board >= NUM_BOARDS || dac >= DACS_PER_BOARD) return;
    resolution_[board][dac] = (resolution_bits == 12) ? 12 : 16;
}

uint8_t BoardManager::get_resolution(uint8_t board, uint8_t dac) {
    if (board >= NUM_BOARDS || dac >= DACS_PER_BOARD) return 16;
    return resolution_[board][dac];
}

void BoardManager::set_controller_serial(const char* sn) {
    strncpy(controller_serial_, sn, SERIAL_NUMBER_MAX_LEN - 1);
    controller_serial_[SERIAL_NUMBER_MAX_LEN - 1] = '\0';
}

const char* BoardManager::get_controller_serial() const {
    return controller_serial_;
}

std::string BoardManager::execute_idn() {
    const char* sn = (controller_serial_[0] != '\0') ? controller_serial_ : "000";
    char buf[128];
    snprintf(buf, sizeof(buf), "greymatter,DAC Controller,%s,0.1", sn);
    return buf;
}

std::string BoardManager::execute_fault_query() {
#ifdef SINGLE_BOARD_MODE
    // Single-board mode: FAULT is NAND of all 3 DAC faults
    // Can only detect "any fault" vs "no fault", not which DAC
    if (spi_.is_fault_active()) {
        return "FAULT:ACTIVE";
    }
    return "OK";
#else
    // Multi-board mode: Per-DAC fault detection via IO expanders
    if (spi_.is_fault_active()) {
        uint32_t faults = spi_.io_expander().read_faults();
        char buf[32];
        snprintf(buf, sizeof(buf), "FAULT:0x%06lX", faults);
        return buf;
    }
    return "OK";
#endif
}
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

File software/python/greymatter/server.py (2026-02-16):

#!/usr/bin/env python3
"""greymatter ZMQ server.

Runs on the host Raspberry Pi that has Pico boards connected via USB.
Accepts SCPI commands over ZMQ and routes them to the appropriate Pico.

Usage::

    python -m greymatter.server
    python -m greymatter.server --port 5556 --scan '/dev/ttyACM*'

The server auto-discovers Pico boards by scanning serial ports and
sending ``*IDN?``.  Each board is assigned a name (``pico_0``, ``pico_1``,
etc.) in the order they are discovered.

Clients connect with::

    gm = GreyMatter(address="<host-ip>", pico="pico_0")
"""

from __future__ import annotations

import argparse
import json
import glob as glob_module
from datetime import datetime

from .transport import SerialTransport
from .errors import GreyMatterError


def _log(msg: str) -> None:
    print(f"[{datetime.now().strftime('%Y-%m-%d %H:%M:%S')}] {msg}", flush=True)


class PicoConnection:
    """Tracks a single Pico board connection."""

    def __init__(self, name: str, port: str, transport: SerialTransport,
                 idn: str):
        self.name = name
        self.port = port
        self.transport = transport
        self.idn = idn


def discover_picos(
    patterns: list[str] | None = None,
    baudrate: int = 115200,
    timeout: float = 2.0,
) -> dict[str, PicoConnection]:
    """Scan serial ports for greymatter Pico boards.

    Returns:
        dict mapping name -> PicoConnection for each board that responds
        to ``*IDN?``.
    """
    if patterns is None:
        patterns = ["/dev/ttyACM*", "/dev/ttyUSB*", "/dev/tty.usbmodem*"]

    ports: list[str] = []
    for pattern in patterns:
        ports.extend(sorted(glob_module.glob(pattern)))

    picos: dict[str, PicoConnection] = {}
    idx = 0
    for port in ports:
        try:
            _log(f"Trying {port} ...")
            transport = SerialTransport(port, baudrate, timeout)
            idn = transport.send_command("*IDN?")

            # Extract serial number from IDN string (field 3 of 4):
            # "greymatter,DAC Controller,<SN>,0.1"
            idn_fields = idn.split(",")
            sn = idn_fields[2].strip() if len(idn_fields) >= 3 else ""

            # Use SN as name if it's set (not "000" or empty)
            if sn and sn != "000":
                name = sn
            else:
                name = f"pico_{idx}"

            picos[name] = PicoConnection(name, port, transport, idn)
            _log(f"  -> {name}: {idn}")
            idx += 1
        except Exception as exc:
            _log(f"  -> skip: {exc}")

    return picos


def _handle_meta(cmd: str, picos: dict[str, PicoConnection],
                 scan_kw: dict) -> str:
    """Handle server meta-commands (prefixed with ``__``)."""
    if cmd == "__list__":
        info = [
            {"name": p.name, "port": p.port, "idn": p.idn}
            for p in picos.values()
        ]
        return json.dumps({"ok": True, "data": info})

    if cmd == "__rescan__":
        for p in picos.values():
            try:
                p.transport.close()
            except Exception:
                pass
        picos.clear()
        picos.update(discover_picos(**scan_kw))
        return json.dumps(
            {"ok": True, "data": f"Found {len(picos)} pico(s)"}
        )

    return json.dumps({"ok": False, "error": f"Unknown meta command: {cmd}"})


def run_server(
    port: int = 5556,
    scan_patterns: list[str] | None = None,
    baudrate: int = 115200,
) -> None:
    """Start the ZMQ server loop.

    Args:
        port: TCP port for the ZMQ REP socket.
        scan_patterns: Glob patterns for serial port discovery.
        baudrate: Baud rate for Pico serial connections.
    """
    import zmq

    _log("Starting greymatter server")

    scan_kw = {"patterns": scan_patterns, "baudrate": baudrate}
    picos = discover_picos(**scan_kw)

    if not picos:
        _log("WARNING: No Pico boards found. Server will still start "
             "(use __rescan__ after connecting boards).")

    _log(f"Managing {len(picos)} Pico board(s)")

    context = zmq.Context()
    socket = context.socket(zmq.REP)
    socket.bind(f"tcp://*:{port}")
    _log(f"Listening on tcp://*:{port}")

    try:
        while True:
            raw = socket.recv_string()

            # Parse request
            try:
                request = json.loads(raw)
            except json.JSONDecodeError:
                socket.send_string(
                    json.dumps({"ok": False, "error": "Invalid JSON"})
                )
                continue

            cmd = request.get("cmd", "")
            pico_name = request.get("pico")

            # Meta commands
            if cmd.startswith("__") and cmd.endswith("__"):
                reply = _handle_meta(cmd, picos, scan_kw)
                socket.send_string(reply)
                continue

            # Resolve which Pico to route to
            if pico_name is None:
                if len(picos) == 1:
                    pico = next(iter(picos.values()))
                elif len(picos) == 0:
                    socket.send_string(json.dumps({
                        "ok": False,
                        "error": "No Pico boards connected"
                    }))
                    continue
                else:
                    socket.send_string(json.dumps({
                        "ok": False,
                        "error": (
                            f"Multiple picos connected, specify one of: "
                            f"{list(picos.keys())}"
                        ),
                    }))
                    continue
            else:
                pico = picos.get(pico_name)
                if pico is None:
                    socket.send_string(json.dumps({
                        "ok": False,
                        "error": (
                            f"Unknown pico '{pico_name}'. "
                            f"Available: {list(picos.keys())}"
                        ),
                    }))
                    continue

            # Forward SCPI command to the Pico
            try:
                _log(f"[{pico.name}] {cmd}")
                result = pico.transport.send_command(cmd)
                socket.send_string(json.dumps({"ok": True, "data": result}))
            except GreyMatterError as exc:
                _log(f"[{pico.name}] ERROR: {exc}")
                socket.send_string(
                    json.dumps({"ok": False, "error": str(exc)})
                )
            except Exception as exc:
                _log(f"[{pico.name}] COMM ERROR: {exc}")
                socket.send_string(json.dumps({
                    "ok": False,
                    "error": f"Communication error: {exc}",
                }))

    except KeyboardInterrupt:
        _log("Shutting down")
    finally:
        for p in picos.values():
            try:
                p.transport.close()
            except Exception:
                pass
        socket.close()
        context.destroy()
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

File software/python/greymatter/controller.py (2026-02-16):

from __future__ import annotations

from .errors import GreyMatterError
from .transport import SerialTransport, ZmqTransport, _CMD_TIMEOUT


class GreyMatter:
    """Top-level driver for the greymatter DAC controller.

    Communicates with the firmware either directly over USB serial
    or remotely via a ZMQ server running on the host machine.

    Direct serial connection::

        gm = GreyMatter("/dev/tty.usbmodem1101")
        gm.board(0).dac(0).channel(0).set_current(50.0)
        gm.close()

    Remote connection via server::

        gm = GreyMatter(address="192.168.1.100", pico="pico_0")
        gm.board(0).dac(0).channel(0).set_current(50.0)
        gm.close()

    As a context manager::

        with GreyMatter("/dev/tty.usbmodem1101") as gm:
            gm.board(0).dac(0).channel(0).set_current(50.0)
    """

    def __init__(
        self,
        port: str | None = None,
        *,
        address: str | None = None,
        pico: str | None = None,
        zmq_port: int = 5556,
        baudrate: int = 115200,
        num_boards: int = 8,
        timeout: float = _CMD_TIMEOUT,
    ):
        self._num_boards = num_boards

        if port is not None:
            self._transport = SerialTransport(port, baudrate, timeout)
        elif address is not None:
            self._transport = ZmqTransport(
                address, pico, zmq_port, timeout=max(timeout, 10.0)
            )
        else:
            raise ValueError(
                "Provide 'port' for direct serial or 'address' for remote"
            )

        # Lazily-constructed board cache
        self._boards: dict[int, "Board"] = {}

    # -- Context manager --

    def __enter__(self):
        return self

    def __exit__(self, *exc):
        self.close()

    def close(self):
        """Close the underlying connection."""
        self._transport.close()

    # -- Navigation --

    def board(self, board_id: int) -> "Board":
        """Return a Board object for the given board index (0-7)."""
        if board_id < 0 or board_id >= self._num_boards:
            raise ValueError(f"board_id must be 0-{self._num_boards - 1}")
        if board_id not in self._boards:
            from .components import Board
            self._boards[board_id] = Board(self, board_id)
        return self._boards[board_id]

    @property
    def channels(self) -> list:
        """Flat list of all Channel objects across all boards."""
        chs = []
        for b in range(self._num_boards):
            board = self.board(b)
            for d in range(3):
                dac = board.dac(d)
                for c in range(dac.num_channels):
                    chs.append(dac.channel(c))
        return chs

    # -- Global commands --

    def identify(self) -> str:
        """Send *IDN? and return the identification string."""
        return self.query("*IDN?")

    def reset(self) -> None:
        """Send *RST to reset all DACs."""
        self.command("*RST")

    def fault_status(self) -> str:
        """Query FAULT? and return the result."""
        return self.query("FAULT?")

    def update_all(self) -> None:
        """Send UPDATE:ALL to update all DAC outputs."""
        self.command("UPDATE:ALL")

    def pulse_ldac(self) -> None:
        """Send LDAC to pulse the load-DAC line."""
        self.command("LDAC")

    @property
    def serial_number(self) -> str:
        """Query the controller serial number (SYST:SN?)."""
        return self.query("SYST:SN?")

    @serial_number.setter
    def serial_number(self, value: str) -> None:
        """Set the controller serial number (SYST:SN <value>)."""
        self.command(f"SYST:SN {value}")

    # -- Raw SCPI --

    def command(self, cmd: str) -> str:
        """Send a SCPI command and return the response.

        Raises GreyMatterError if the firmware returns an ERROR: response.
        """
        resp = self._transport.send_command(cmd)
        if resp.startswith("ERROR:"):
            raise GreyMatterError(resp)
        return resp

    def query(self, cmd: str) -> str:
        """Send a SCPI query and return the response string.

        Raises GreyMatterError if the firmware returns an ERROR: response.
        """
        return self.command(cmd)

    # -- Server utilities --

    @staticmethod
    def list_picos(
        address: str, zmq_port: int = 5556, timeout: float = 5.0
    ) -> list[dict]:
        """Query the server for a list of connected Pico boards.

        Returns a list of dicts with keys: name, port, idn.

        Example::

            picos = GreyMatter.list_picos("192.168.1.100")
            for p in picos:
                print(f"{p['name']} on {p['port']}: {p['idn']}")
        """
        import json
        import zmq

        context = zmq.Context()
        socket = context.socket(zmq.REQ)
        socket.setsockopt(zmq.RCVTIMEO, int(timeout * 1000))
        socket.setsockopt(zmq.LINGER, 1000)
        socket.connect(f"tcp://{address}:{zmq_port}")
        try:
            socket.send_string(json.dumps({"cmd": "__list__"}))
            reply = json.loads(socket.recv_string())
            if reply.get("ok"):
                return reply["data"]
            raise GreyMatterError(reply.get("error", "Unknown error"))
        finally:
            socket.close()
            context.destroy()

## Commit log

2025-12-28 specified hardware pin mappings for I/O expander
2025-12-28 support for DAC calibration
2026-02-04 added mode for single microcyte board (no I/O expander)
2026-02-04 set_span_all command should use the correct SPI command
    [board_manager.cpp, board_manager.hpp]
2026-02-05 fixed SPI vs. GPIO init order
    [spi_manager.cpp]
2026-02-05 12-bit data word fix
    [ltc2662.cpp, ltc2664.cpp]
2026-02-05 FAULT pin is push-pull not active-low
2026-02-05 test waveforms for SPI logic
2026-02-05 forgot to return code in current to code function
2026-02-06 python driver
2026-02-10 RPi Pico PMOD PCB
    [pico2-spi-pmod.kicad_pcb, pico2-spi-pmod.kicad_sch]
2026-02-10 microcyte DAC PCB
    [microcyte.kicad_pcb, microcyte.kicad_sch]
2026-02-10 greymatter-single PCB
    [greymatter-single.kicad_pcb, greymatter-single.kicad_sch]
2026-02-10 ignored KiCAD files
2026-02-10 progress on full 8x8 motherboard PCB
    [giona_8x8_carrier.kicad_sch, greymatter-mobo.kicad_pcb, greymatter-mobo.kicad_sch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]
2026-02-16 pico 2 has 4MB flash
